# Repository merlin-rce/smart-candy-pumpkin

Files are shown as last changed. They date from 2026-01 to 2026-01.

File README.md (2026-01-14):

<div align="center">

# 🎃 The Smart Candy Pumpkin

**An ESP32-powered, motion-activated Halloween candy dispenser**






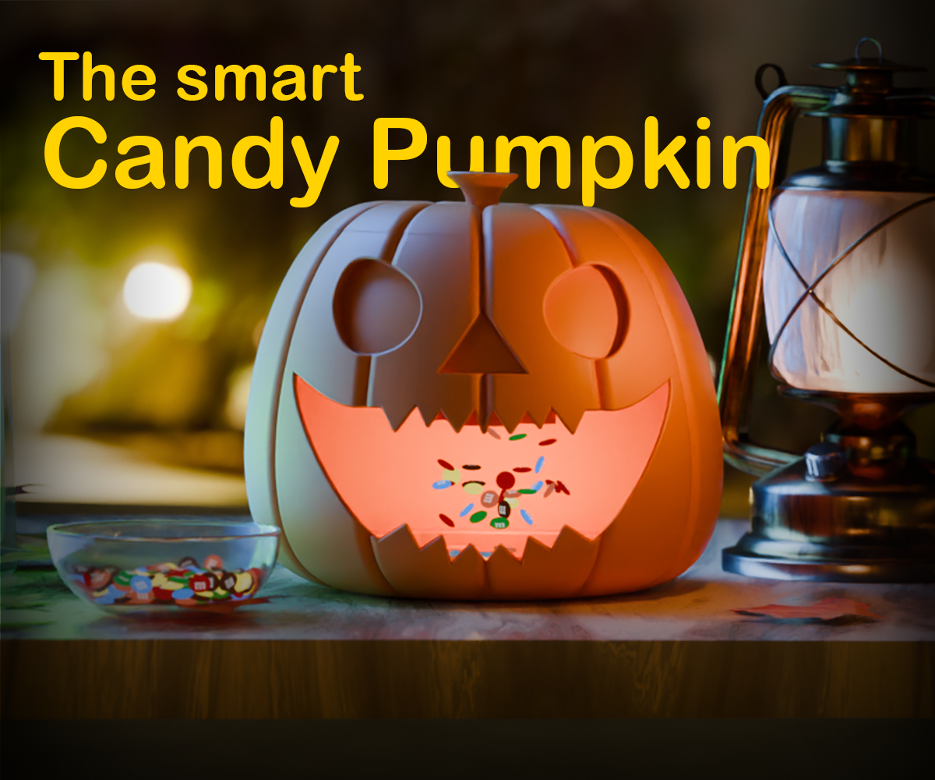
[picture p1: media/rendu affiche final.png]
Smart Candy Pumpkin


*A living, interactive pumpkin that surprises trick-or-treaters by automatically dispensing candy!*

[Features](#-features) • [Quick Start](#-quick-start) • [Build Guide](docs/BUILD_GUIDE.md) • [Parts List](#-bill-of-materials) • [3D Files](#-3d-printed-parts)

</div>

---

## 📖 About This Project

Halloween is that magical time of year when creativity meets fright — and candy flows like never before.

The **Smart Candy Pumpkin** is a motion-activated, ESP32-powered pumpkin that automatically dispenses candy when you place your hand inside its mouth. Inside, a hidden servo and ultrasonic sensor detect movement and trigger a rotating wheel that drops a handful of sweets.

> 🎓 **Made by students:** We're two 17-year-old students from Switzerland, passionate about electronics, 3D printing, and creative projects. This is our first full project!

| Difficulty | Build Time | Cost |
|:---:|:---:|:----:|
| ★★★☆☆ Intermediate | 4–6 hours | ~25–40 € |

---

## ✨ Features

- 🖐️ **Motion Detection** — Ultrasonic sensor triggers when a hand enters
- ⚙️ **Automatic Dispensing** — Servo-driven wheel releases candy portions
- 🔋 **Rechargeable** — USB-C charging with 10000mAh Li-Po battery
- 🎨 **Fully 3D Printed** — Complete enclosure with modular design
- 📱 **ESP32-S3 Powered** — Modern microcontroller with plenty of room for expansion
- 🔧 **Easy to Build** — Designed for makers of all levels

---

## 🔧 How It Works

```
┌─────────────────────────────────────────────────────────────┐
│                    SMART CANDY PUMPKIN                      │
├─────────────────────────────────────────────────────────────┤
│                                                             │
│   ┌───────────┐    ┌──────────┐    ┌──────────┐             │
│   │ Ultrasonic│──▶│   ESP32  │───▶│  Servo   │             │
│   │  Sensor   │    │   S3     │    │  Motor   │             │
│   └───────────┘    └──────────┘    └──────────┘             │
│        │                │              │                    │
│   Detects hand    Processes      Rotates candy              │
│   < threshold      signal          wheel                    │
│                                                             │
│   ┌────────────────────────────────────────────┐            │
│   │     Power System (3.7V → 5V)               │            │
│   │  Li-Po ──▶ TP4056 ──▶ DC Booster ──▶ 5V  │            │
│   └────────────────────────────────────────────┘            │
└─────────────────────────────────────────────────────────────┘
```

1. **Detection** — The HC-SR04 ultrasonic sensor continuously monitors the inside of the pumpkin
2. **Processing** — When distance drops below threshold, ESP32 triggers the dispensing sequence
3. **Dispensing** — The servo rotates the 3D-printed wheel, releasing candy through the mouth
4. **Reset** — System returns to monitoring mode, ready for the next trick-or-treater

---

## 🚀 Quick Start

### Prerequisites

- Arduino IDE or PlatformIO
- ESP32 board support installed
- Required libraries: `ESP32Servo`, `Ultrasonic`

### Installation

```bash
# Clone the repository
git clone https://github.com/yourusername/smart-candy-pumpkin.git
cd smart-candy-pumpkin

# Open in Arduino IDE or PlatformIO
# Select board: ESP32S3 Dev Module
# Upload the code
```

### Pin Configuration

| Component | Pin | Wire Color |
|---|-----|---|
| Servo Signal | GPIO 14 | White/Yellow |
| Ultrasonic TRIG | GPIO 16 | Blue |
| Ultrasonic ECHO | GPIO 15 | Yellow |
| Servo VCC | 5V (from booster) | Red |
| Servo GND | GND | Black |
| Sensor VCC | 5V (from booster) | Red |
| Sensor GND | GND | Black |

---

## 📦 Bill of Materials

### ⚡ Power & Charging

| Component | Qty | Link |
|---|:---:|---|
| Type-C Li-Po Charging Module (TP4056 HW-373) | 1 | [AliExpress](https://shorturl.at/nKeuP) |
| 3.7V Li-Po Battery (10000mAh) | 1 | [AliExpress](https://shorturl.at/S42xR) |
| DC-DC Step-Up Converter MT3608 (5V output) | 1 | [AliExpress](https://shorturl.at/hy9fU) |
| Mini Toggle Switch | 1 | — |
| USB Type-C Cable | 1 | — |

### 🧠 Control & Sensors

| Component | Qty | Link |
|---|:---:|---|
| ESP32-S3 Dev Board (N16R8 solderless) | 1 | [AliExpress](https://shorturl.at/64Qph) |
| HC-SR04 Ultrasonic Sensor | 1 | [AliExpress](https://shorturl.at/7jW49) |
| Servo Motor (SG90 or MG90S) | 1 | [AliExpress](https://shorturl.at/Mjuy7) |

### 🖨️ 3D Printing & Hardware

| Component | Qty | Link |
|---|:---:|---|
| PLA Filament Orange (~800g) | 1 | [BambuLab PLA Matte](https://shorturl.at/Oiv1V) |
| PLA Filament Green (small amount) | 1 | — |
| PLA Filament Black (small amount) | 1 | — |
| Round Magnets D6x2mm | 6-8 | [BambuLab Magnets](https://eu.store.bambulab.com/) |

### 🔧 Tools

- Soldering station + solder wire
- Wire cutter / stripper
- Heat-shrink tubing assortment
- Hot glue gun
- Multimeter (recommended)
- 3D Printer access

---

## 🖨️ 3D Printed Parts

All STL files are located in the [`3d-models/`](3d-models/) folder:

| Part | File | Quantity | Color |
|---|---|:---:|---|
| Bottom Base | [`Bottom Base.stl`](3d-models/Bottom%20Base.stl) | 1 | Orange |
| Inner Cover | [`Inner Cover.stl`](3d-models/Inner%20Cover.stl) | 1 | Orange |
| Mid-Mouth Section | [`Mid-Mouth Section.stl`](3d-models/Mid-Mouth%20Section.stl) | 1 | Orange |
| Upper Mouth Section | [`Upper Mouth Section.stl`](3d-models/Upper%20Mouth%20Section.stl) | 1 | Orange |
| Candy Funnel Top | [`Candy Funnel Top.stl`](3d-models/Candy%20Funnel%20Top.stl) | 1 | Orange |
| Stem Cap | [`Stem Cap.stl`](3d-models/Stem%20Cap.stl) | 1 | Green |
| Servo Wheel | [`Servo Wheel.stl`](3d-models/Servo%20Wheel.stl) | 1 | Black |
| Alignment Connector | [`Alignement Connector.stl`](3d-models/Alignement%20Connector.stl) | 6 | Orange |

### Print Settings

| Setting | Value |
|---|---|
| Layer Height | 0.16 mm |
| Infill | 15–20% |
| Supports | Yes (except cable channels) |
| Total Time | ~22 hours |
| Total Filament | ~800g |

> 📥 **Ready-to-print profiles available on [MakerWorld](https://makerworld.com/fr/models/1973808-the-smart-candy-pumpkin)**

---

## 💻 Code

The Arduino sketch is located in the `code/` folder. See the full code in [`code/Smart_Candy_Pumpkin.ino`](code/Smart_Candy_Pumpkin.ino).

### Key Configuration

```cpp
#define SERVO_PIN       14    // Servo signal pin
#define TRIG_PIN        16    // Ultrasonic trigger
#define ECHO_PIN        15    // Ultrasonic echo
#define DIST_THRESHOLD  15    // Detection distance (cm)
```

### Required Libraries

Install via Arduino Library Manager:
- **ESP32Servo** by Kevin Harrington & John K. Bennett
- **Ultrasonic** by Erick Simões

### Upload Instructions

1. Open Arduino IDE
2. Go to **File → Preferences** and add ESP32 board URL:
   ```
   https://raw.githubusercontent.com/espressif/arduino-esp32/gh-pages/package_esp32_index.json
   ```
3. Install ESP32 board package via **Tools → Board → Boards Manager**
4. Select **ESP32S3 Dev Module**
5. Connect via USB and select the correct port
6. Click **Upload** (hold BOOT button if needed)

---

## ⚠️ Safety Notes

> **This project involves electronics, soldering, and Li-Po batteries. Please read carefully.**

| ⚡ Electrical | 🔋 Battery | 🔥 Soldering |
|---|---|---|
| Always unplug before wiring | Never puncture or bend | Wear safety glasses |
| Double-check polarity (+/–) | Don't charge unattended | Work in ventilated area |
| Use multimeter to verify | Keep away from heat | Use proper iron stand |

---

## 🗂️ Repository Structure

```
smart-candy-pumpkin/
├── 📄 README.md                    # This file
├── 📄 LICENSE                      # CC BY-NC-SA 4.0
├── 📁 code/                        # Arduino source code
│   └── Smart_Candy_Pumpkin.ino
├── 📁 docs/                        # Documentation
│   └── BUILD_GUIDE.md              # Step-by-step build guide
├── 📁 3d-models/                   # All 3D printable STL files
│   ├── Bottom Base.stl
│   ├── Inner Cover.stl
│   ├── Mid-Mouth Section.stl
│   ├── Upper Mouth Section.stl
│   ├── Candy Funnel Top.stl
│   ├── Stem Cap.stl
│   ├── Servo Wheel.stl
│   └── Alignement Connector.stl
├── 📁 media/                       # Renders & videos
│   ├── rendu *.png                 # 3D renders
│   └── animation *.mp4             # Demo video
└── 📁 .github/
    └── FUNDING.yml                 # Sponsorship info
```

---

## 🔮 Future Improvements

- [ ] Adjustable candy portion size
- [ ] LED eyes with spooky effects
- [ ] Sound effects (screams, laughs)
- [ ] Power-saving deep sleep mode
- [ ] Wi-Fi configuration portal
- [ ] Candy count tracker

---

## 🙏 Acknowledgments

- **3D Renders:** Kwama Muhoto Tevin — for the amazing visuals
- **Workshop Support:** CPNE – ELN Department — for tools and materials
- **Build Assistance:** Alessio Castorina — for the help and fast deliveries

---

## 📚 Resources

| Resource | Description |
|---|---|
| 📖 [Build Guide](docs/BUILD_GUIDE.md) | Detailed step-by-step instructions |
| 🌐 [Instructables](https://www.instructables.com/The-Smart-Candy-Pumpkin/) | Original tutorial with time-lapse videos |
| 🔌 [Circuit Diagram](https://app.cirkitdesigner.com/project/bdcf653b-0cb5-4596-8416-652c75baebec) | Interactive wiring schematic |
| 🖨️ [MakerWorld](https://makerworld.com/fr/models/1973808-the-smart-candy-pumpkin) | Ready-to-print slicer profiles |

---

## 📜 License

This project is licensed under **[CC BY-NC-SA 4.0](https://creativecommons.org/licenses/by-nc-sa/4.0/)** — see the [LICENSE](LICENSE) file for details.

You are free to share and adapt this project for **non-commercial purposes**, as long as you give appropriate credit and share your modifications under the same license.

---

<div align="center">

**Made with ❤️ in Switzerland**

If you enjoyed this project, consider supporting us!



⭐ **Star this repo** if you found it helpful!

</div>

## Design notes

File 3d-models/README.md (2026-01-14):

# 🖨️ 3D Models

This folder contains all the STL files needed to print the Smart Candy Pumpkin.

## Parts List

| File | Quantity | Color | Description |
|---|:---:|---|---|
| `Bottom Base.stl` | 1 | 🟠 Orange | Holds battery, ESP32, and electronics |
| `Inner Cover.stl` | 1 | 🟠 Orange | Hides electronics (removable) |
| `Mid-Mouth Section.stl` | 1 | 🟠 Orange | Contains servo, sensor, and candy chute |
| `Upper Mouth Section.stl` | 1 | 🟠 Orange | Top of mouth with eyes |
| `Candy Funnel Top.stl` | 1 | 🟠 Orange | Where you pour candies in |
| `Stem Cap.stl` | 1 | 🟢 Green | The pumpkin stem |
| `Servo Wheel.stl` | 1 | ⚫ Black | Rotating disk that releases candy |
| `Alignement Connector.stl` | 6 | 🟠 Orange | Connects sections together |

## Print Settings

| Setting | Recommended Value |
|---|---|
| Material | PLA |
| Layer Height | 0.16 mm |
| Infill | 15–20% |
| Supports | Yes (see note below) |
| Build Plate | Textured preferred |

> ⚠️ **Important:** Disable supports inside the cable management channel of the Bottom Base, otherwise wires won't fit through!

## Print Stats

- ⏱️ **Total time:** ~22 hours
- 🧵 **Filament used:** ~800g

## Ready-to-Print Profiles

Pre-configured slicer profiles for Bambu Lab printers are available on MakerWorld:

👉 [Download from MakerWorld](https://makerworld.com/fr/models/1973808-the-smart-candy-pumpkin)

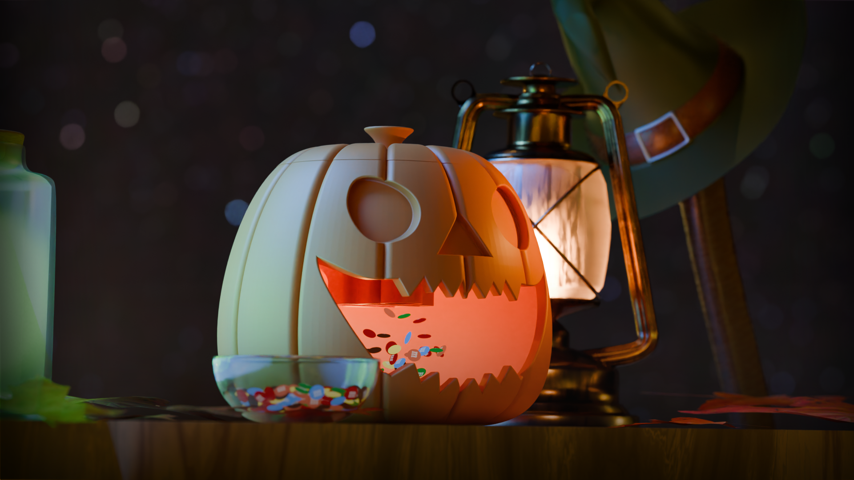
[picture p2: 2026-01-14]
media/rendu 8 effet.png

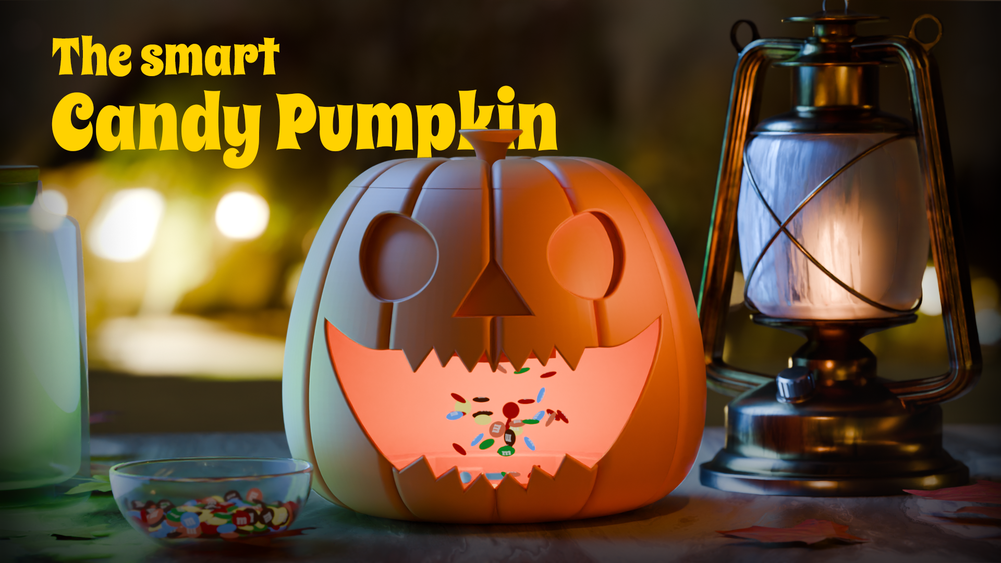
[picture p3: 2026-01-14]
media/affiche variante (1920 x 1080).png

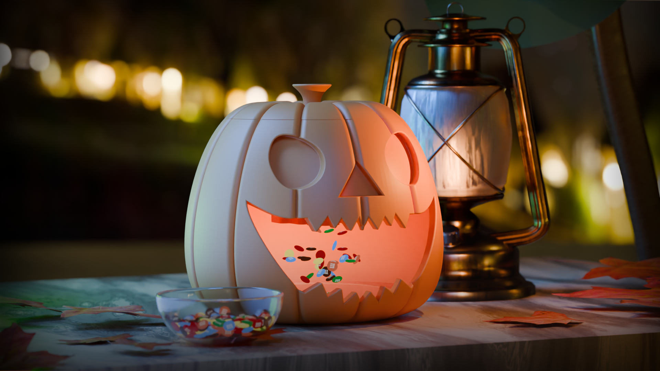
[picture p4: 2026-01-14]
media/rendu 1 effet.png

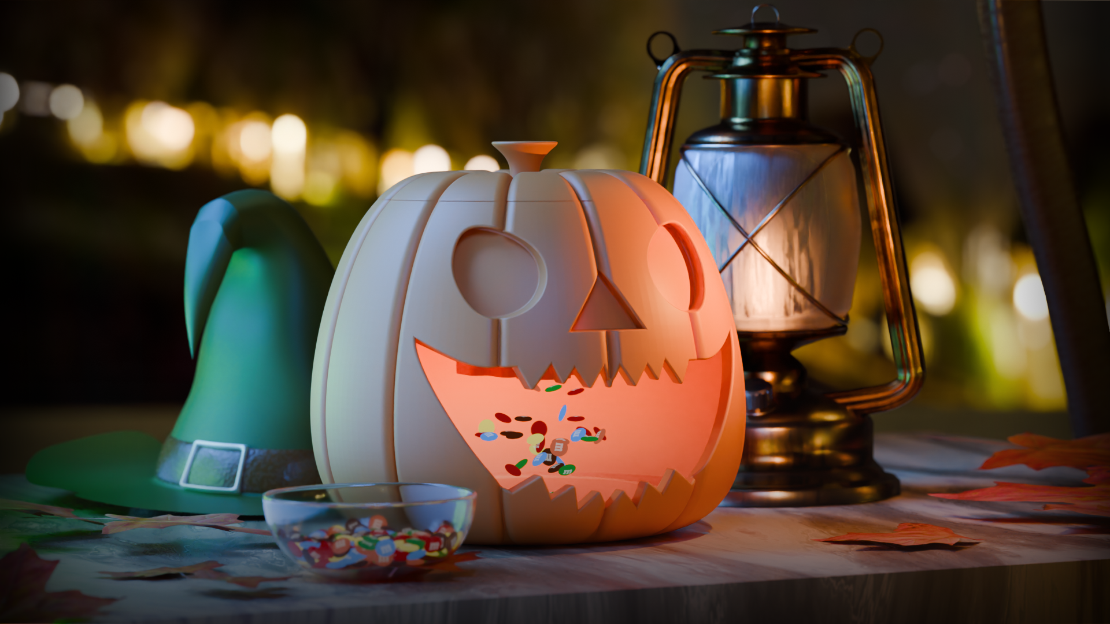
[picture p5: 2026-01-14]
media/rendu 2 effet.png

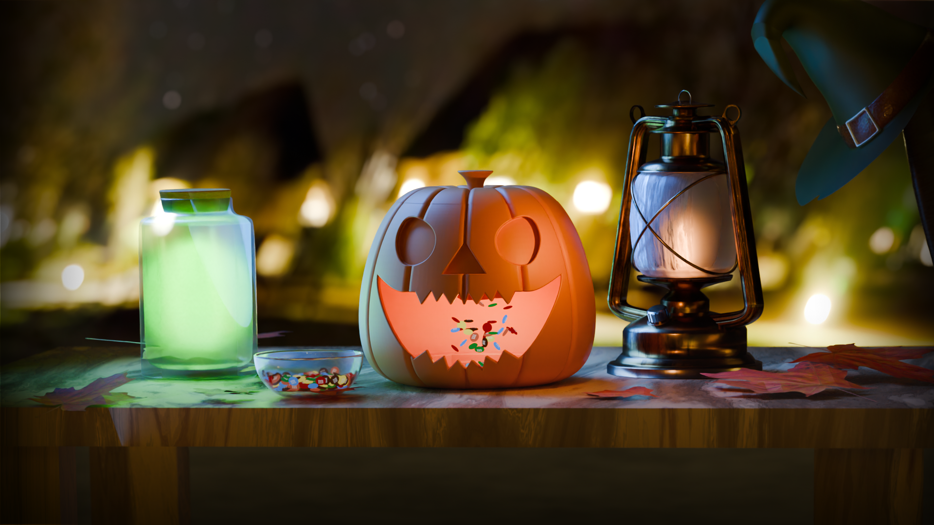
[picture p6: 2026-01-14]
media/rendu 5 effet.png

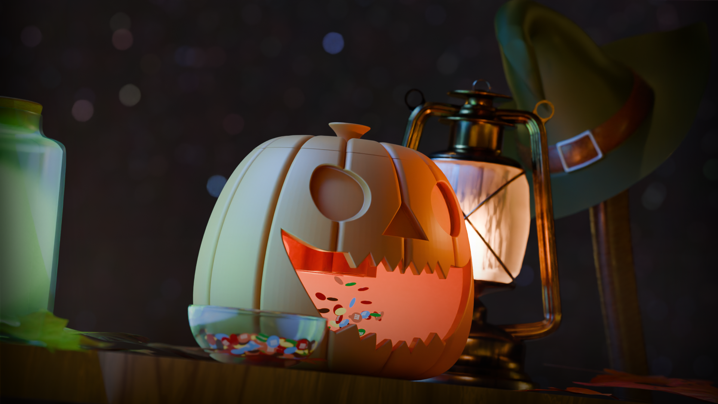
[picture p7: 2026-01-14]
media/rendu 7 effet.png

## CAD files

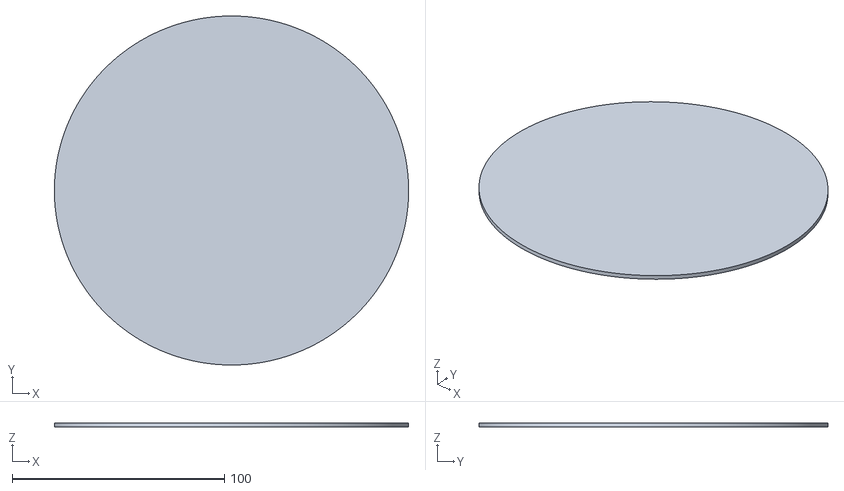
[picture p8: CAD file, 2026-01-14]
3d-models/Inner Cover.stl
167.0 x 164.6 x 2.00

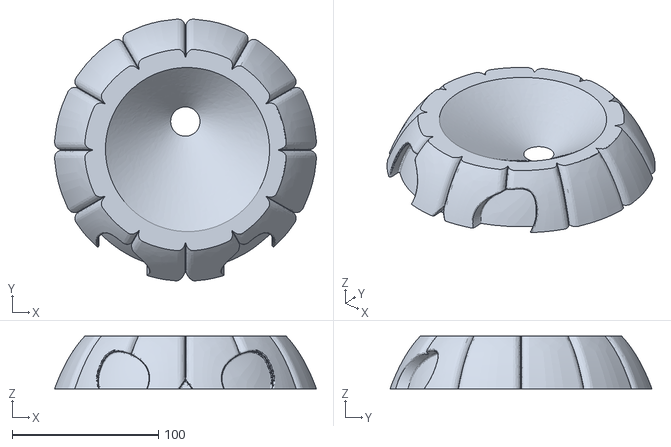
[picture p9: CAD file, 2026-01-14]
3d-models/Upper Mouth Section.stl
179.0 x 179.0 x 36.1

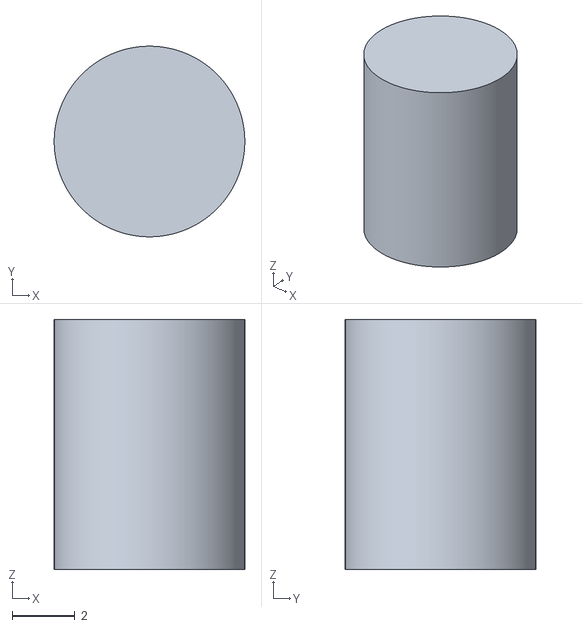
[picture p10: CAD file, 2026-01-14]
3d-models/Alignement Connector.stl
6.10 x 6.10 x 8.00

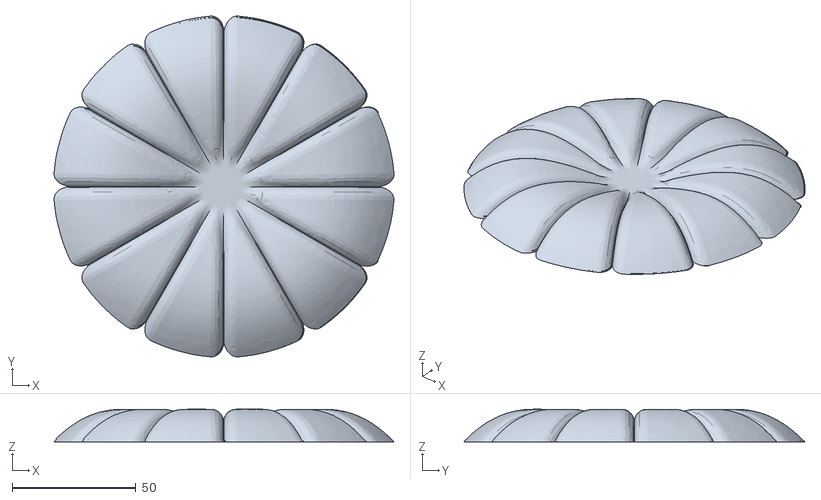
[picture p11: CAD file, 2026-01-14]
3d-models/Candy Funnel Top.stl
137.2 x 137.5 x 13.1

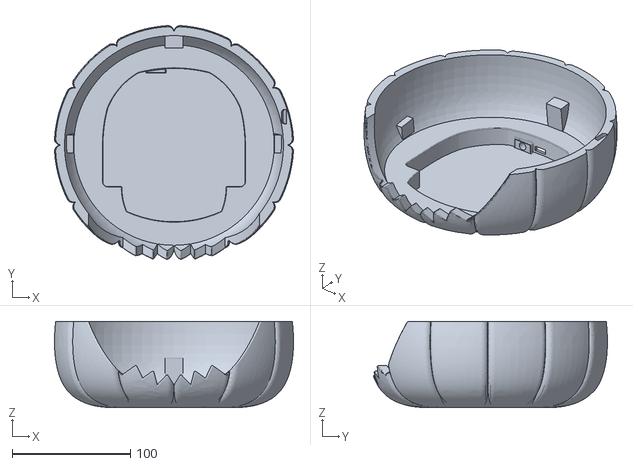
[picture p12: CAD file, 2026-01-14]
3d-models/Bottom Base.stl
202.0 x 197.6 x 72.7

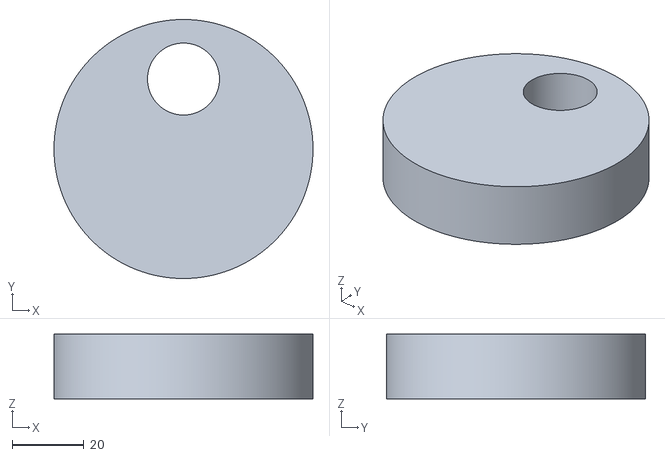
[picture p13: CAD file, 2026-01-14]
3d-models/Servo Wheel.stl
72.0 x 72.0 x 18.0

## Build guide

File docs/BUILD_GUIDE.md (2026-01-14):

# 📖 Smart Candy Pumpkin — Complete Build Guide

This guide contains detailed step-by-step instructions for building the Smart Candy Pumpkin from start to finish.

> 🎥 **Video tutorials available:** Check out our [Instructables page](https://www.instructables.com/The-Smart-Candy-Pumpkin-/) for time-lapse videos of each step.

---

## Table of Contents

1. [Safety & Preparation](#1-safety--preparation)
2. [Wiring Overview](#2-wiring-overview)
3. [Adding the Power Switch](#3-adding-the-power-switch)
4. [Connecting Charger to DC Booster](#4-connecting-the-charger-to-the-dc-booster)
5. [Connecting Battery to Charger](#5-connecting-the-battery-to-the-charging-module)
6. [Wiring the Ultrasonic Sensor](#6-wiring-the-ultrasonic-sensor)
7. [Preparing the Servo Connection](#7-preparing-the-servo-connection)
8. [Power Wiring to Booster](#8-power-wiring-servo--sensor-to-the-booster)
9. [Wiring to ESP32](#9-wiring-everything-to-the-esp32)
10. [Uploading the Code](#10-uploading-the-code-to-the-esp32)
11. [3D Printing](#11-3d-printing-the-pumpkin)
12. [Gluing Stem & Placing Magnets](#12-gluing-the-pumpkin-stem-and-placing-magnets)
13. [Assembling Candy Funnel](#13-assembling-the-candy-funnel-with-upper-mouth-section)
14. [Routing Wires](#14-routing-the-wires-to-the-bottom-base)
15. [Mounting Electronics](#15-mounting-the-electronics-in-the-bottom-base)
16. [Final Assembly](#16-final-pumpkin-assembly)
17. [Testing & Completion](#17-the-pumpkin-comes-to-life)

---

## 1. Safety & Preparation

Before bringing your pumpkin to life, let's make sure everything stays safe — both for you and your workspace.

### ⚠️ Safety Guidelines

| Category | Precautions |
|---|---|
| **Electrical** | Always unplug power before wiring or soldering. Double-check all battery polarities (+/–). |
| **Li-Po Battery** | Handle with care — never bend, puncture, or charge unattended. Place on non-flammable surface while charging. |
| **Soldering** | Wear protective glasses, work in ventilated area, use proper stand for your iron. |
| **3D Printing** | Let parts cool completely before assembly. Trim off sharp edges or support marks. |

### 💡 Pro Tips

- A multimeter is your best friend — always check voltage before powering your ESP32
- Hot glue and Li-Po cells don't mix! Keep glue away from batteries and wires

---

## 2. Wiring Overview

Before starting the build, here's how every component connects together.

### 📐 Full Circuit Diagram

👉 **Interactive circuit:** [View on Cirkit Designer](https://app.cirkitdesigner.com/project/bdcf653b-0cb5-4596-8416-652c75baebec)

### Pin Connections

#### Servo Motor
| Wire | Connection |
|---|---|
| White (Signal) | GPIO 14 on ESP32 |
| Red (VCC) | 5V output from booster |
| Black (GND) | GND output from booster |

#### Ultrasonic Sensor (HC-SR04)
| Pin | Connection |
|-----|---|
| VCC | 5V output from booster |
| GND | GND output from booster |
| TRIG | GPIO 16 (blue wire) |
| ECHO | GPIO 15 (yellow wire) |

#### Power System
```
Battery (3.7V) → HW-373 Type-C Charger
├── Red (+) → B+
└── Black (–) → B-

HW-373 Output → MT3608 Booster Input
├── OUT+ → VIN+ (red)
└── OUT– → VIN– (black)
```

> 🧠 **Tip:** Always double-check the polarity (+/–) before powering on. A wrong connection can damage the ESP32 or booster.

---

## 3. Adding the Power Switch

We're adding a small toggle switch to control power between the battery and the circuit.

### Steps

1. **Trim the switch** — It's a 3-pin toggle. Cut off the third pin (unused)
2. **Cut the battery's red wire** in half. You now have two ends: one from the battery, one going to the circuit
3. **Strip & tin** both ends with a bit of solder
4. **Slide heat-shrink tube** on the battery side before soldering
5. **Solder connections:**
   - Battery wire → left lug
   - Circuit wire → right lug
6. **Shrink the tubing** with a lighter — quick passes, no flames near the Li-Po!

✅ You now have a clean power switch inline with the battery.

---

## 4. Connecting the Charger to the DC Booster

Linking the Type-C charging module to the DC-DC booster for 5V output.

### Steps

1. **Prepare two short wires** — just long enough from charger to booster
2. **Strip and tin** both ends of each wire
3. **Solder to charging module** — use the output pads (NOT BAT+/BAT–)
4. **Solder to DC booster** — VIN+ and VIN– pads
5. **Verify polarity:** + → +, – → –
6. **Adjust output voltage:**
   - Plug USB-C cable into charger
   - Use small screwdriver to turn the adjustment screw
   - Adjust until output reads **5.0V** (check with multimeter)
7. **Add heat-shrink tubing** for insulation

✅ Charger and booster now deliver clean 5V output!

---

## 5. Connecting the Battery to the Charging Module

Soldering the Li-Po battery directly to the Type-C charging board.

### Steps

1. Take the battery leads:
   - **Red = +**
   - **Black = –**
2. **Tin both ends**
3. **Solder:**
   - Red → B+
   - Black → B–
4. **Add heat-shrink** before soldering, then slide over joints
5. **Shrink carefully** with lighter — short passes, keep flame away from Li-Po!

✅ Battery is now safely connected to the charger.

---

## 6. Wiring the Ultrasonic Sensor

Preparing clean, removable connections for the HC-SR04 sensor.

### Steps

1. **Prepare 4-wire ribbon cable** (red, black, yellow, blue) with female connector end
2. **Tin all four wires** on the open side
3. **Remove default header** from sensor by adding solder to pins
4. **Solder wires directly to sensor:**
   | Pin | Wire Color |
   |-----|------------|
   | VCC | Red 🔴 |
   | GND | Black ⚫ |
   | Echo | Yellow 🟡 |
   | Trig | Blue 🔵 |
5. **Prepare male pins:** Take 4 male-to-male pins, tin shorter side
6. **Solder each color wire** to matching pin
7. **Add heat-shrink** over every joint

✅ You now have a plug-and-play ultrasonic sensor cable!

---

## 7. Preparing the Servo Connection

Creating a detachable connector for the servo motor.

### Steps

1. **Cut three short wires:** black, red, yellow
2. **Strip and tin** both ends of each wire
3. **Take three male-to-male pins** and solder wires to short side
4. **Add heat-shrink tubing** and shrink with lighter
5. **Match colors on servo side:**
   | Servo Wire | Your Wire |
   |------------|-----------|
   | Black | Black ⚫ |
   | Red | Red 🔴 |
   | White | Yellow 🟡 |

✅ You have a detachable 3-pin servo connector!

---

## 8. Power Wiring: Servo + Sensor to the Booster

Connecting 5V and GND for servo and sensor to the DC booster output.

### Steps

**For 5V (Red wires):**
1. Take red wire from servo + red wire from sensor + extra red wire (for ESP32)
2. Strip and tin loose ends
3. Twist all three red wires together
4. Slide small heat-shrink behind them
5. Solder bundle to **V-OUT+** pad on DC booster
6. Add larger heat-shrink over the group

**For GND (Black wires):**
1. Repeat same process with black wires
2. Twist together, tin, solder to **V-OUT–**
3. Finish with heat-shrink tubing

✅ Servo, sensor, and ESP32 now share 5V and ground from booster!

---

## 9. Wiring Everything to the ESP32

Final soldering connections to the ESP32 board.

### Signal Connections

| Wire | ESP32 Pin |
|---|---|
| Trigger (blue) | GPIO 16 |
| Echo (yellow) | GPIO 15 |
| Servo signal (yellow) | GPIO 14 |

### Power Connections

| Wire | ESP32 Pin |
|---|---|
| Red (from booster V-OUT+) | 5V |
| Black (from booster V-OUT–) | GND |

### Steps

1. **Tin each wire**
2. **Insert through corresponding hole** on ESP32
3. **Solder from back side**
4. **Trim wire ends** so they don't stick out

> ⚠️ **Tip:** Keep all connections on the same side of the board for clean, flat assembly.

✅ ESP32 is fully wired and ready!

---

## 10. Uploading the Code to the ESP32

Time to give your pumpkin a brain! 🧠🎃

### Step 1: Install Arduino IDE

Download from [arduino.cc](https://www.arduino.cc/en/software)

### Step 2: Add ESP32 Board Support

1. Open Arduino IDE → **File → Preferences**
2. In "Additional Boards Manager URLs", paste:
   ```
   https://raw.githubusercontent.com/espressif/arduino-esp32/gh-pages/package_esp32_index.json
   ```
3. Click OK

### Step 3: Install ESP32 Package

1. Go to **Tools → Board → Boards Manager**
2. Search for "esp32"
3. Install package by **Espressif Systems**
4. Select **Tools → Board → ESP32 Arduino → ESP32S3 Dev Module**

### Step 4: Install Required Libraries

Go to **Sketch → Include Library → Manage Libraries** and install:
- **ESP32Servo** by Kevin Harrington & John K. Bennett
- **Ultrasonic** by Erick Simões

### Step 5: Configure the Code

Open `code/Smart_Candy_Pumpkin.ino` and verify pins match your build:
```cpp
#define SERVO_PIN       14
#define TRIG_PIN        16
#define ECHO_PIN        15
#define DIST_THRESHOLD  15  // cm
```

### Step 6: Upload

1. Connect ESP32 via USB (use the USB port, not UART)
2. Select correct port under **Tools → Port**
3. Click **Upload (▶)**
4. If upload doesn't start, hold **BOOT** button until flashing begins

### Testing

1. Open **Serial Monitor** (115200 baud)
2. Move hand inside pumpkin area
3. Servo should spin and "drop candy"

✅ ESP32 is programmed!

---

## 11. 3D Printing the Pumpkin

The model is split into 8 printable parts for easy assembly.

### Parts List

| Part | Color | Qty |
|---|---|:---:|
| Bottom Base | Orange 🟠 | 1 |
| Inner Cover | Orange 🟠 | 1 |
| Mid-Mouth Section | Orange 🟠 | 1 |
| Upper Mouth Section | Orange 🟠 | 1 |
| Candy Funnel Top | Orange 🟠 | 1 |
| Stem Cap | Green 🟢 | 1 |
| Servo Wheel | Black ⚫ | 1 |
| Alignment Connector | Orange 🟠 | 6 |

### Print Settings

| Setting | Value |
|---|---|
| Layer Height | 0.16 mm |
| Infill | 15–20% |
| Plate | Textured build plate |
| Supports | Normal (see note below) |

> ⚠️ **Important:** Disable supports inside the cable management area of the Bottom Base — otherwise wires won't fit through!

### Stats

- ⏱️ Total print time: ~22 hours (Bambu Lab P1S)
- 🧵 Filament used: ~800g PLA

### Download Files

- STL files included in repository root
- Ready-to-print profiles: [MakerWorld](https://makerworld.com/fr/models/1973808-the-smart-candy-pumpkin)

✅ Print all parts before continuing!

---

## 12. Gluing the Pumpkin Stem and Placing Magnets

### Attaching the Stem

1. Take the small **green stem**
2. Apply small drop of **super glue** to center of top cap
3. Press firmly for a few seconds
4. Let dry

### Placing the Magnets

The underside of the top cap has small round holes for magnets.

> ⚠️ **Critical:** Check magnet polarity before inserting!

1. Take two magnets and stick them together (shows attracting faces)
2. Slide one magnet into hole (should fit snugly)
3. For matching part, use second magnet (still attached) to find correct orientation
4. Separate gently and insert second magnet

> ✨ No glue needed — friction fit holds them in place!

---

## 13. Assembling the Candy Funnel with Upper Mouth Section

### Steps

1. **Place servo motor** into dedicated slot in Mid-Mouth Section
2. **Insert black Servo Wheel** from other side
3. **Secure with screw** from servo kit
   - ⚠️ Don't overtighten — servo needs to rotate freely!
4. **Insert ultrasonic sensor** into its opening
5. **Pass wires** through cable hole behind it
6. **Add double-sided tape** under sensor to secure (no tape under servo!)
7. **Align Candy Funnel Top** with Upper Mouth Section
8. **Insert plastic connection cylinders** into large holes
9. **Apply glue** on cylinders
10. **Press parts together** firmly until glue sets

> ⚠️ Don't attach this assembly to rest of pumpkin yet!

✅ Servo and sensor installed, funnel attached!

---

## 14. Routing the Wires to the Bottom Base

Passing all wires through the built-in cable tunnel.

### Steps

1. Take a piece of **fishing line** (or thin strong wire)
2. **Tie servo and sensor wires** together at one end of fishing line
3. From Bottom Base, **feed fishing line up** through cable passage
4. **Pull fishing line back down**, bringing wires with it
   - Go slowly — passage is tight!
5. **Tape or glue wires** along top edge inside pumpkin

✅ Wires routed cleanly from top to bottom!

---

## 15. Mounting the Electronics in the Bottom Base

### Placement

1. **Battery** — Stick in center with double-sided tape. Route cables behind it.
2. **ESP32** — Place at bottom, secure with tape
3. **Power switch** — Insert into side hole
4. **Charging module** — Mount in slot, align USB-C port with external hole
5. **DC booster** — Stick next to charger with tape
6. **Flatten wires** along walls for clean finish

✅ All electronics securely placed!

---

## 16. Final Pumpkin Assembly

### Steps

1. Place **Inner Cover** — rests on inner ledge in Bottom Base
   - ⚠️ Don't glue! Keeps it removable for maintenance
2. Take **Bottom Base** and **Mid-Mouth Section**
3. Insert **plastic connection cylinders** into large holes
4. Apply **small drop of glue** on each cylinder
5. **Press parts together** carefully until aligned
6. Hold a few seconds for glue to set

✅ Pumpkin body fully assembled!

---

## 17. The Pumpkin Comes to Life!

🎉 **Congratulations!** Your Smart Candy Pumpkin is complete!

### Final Steps

1. Fill the funnel with M&M's or your favorite candies 🍬
2. Flip the power switch
3. Watch the magic happen!

### Troubleshooting

| Issue | Solution |
|---|---|
| Servo doesn't move | Check wiring, verify 5V from booster |
| No detection | Adjust `DIST_THRESHOLD` in code |
| Servo moves wrong direction | Swap open/close angles in code |
| ESP32 won't upload | Hold BOOT button during upload |

---

## 🎃 Enjoy Your Creation!

You've built a full Halloween robot — great job! 👏

### Share Your Build

- 💬 Leave a comment on our [Instructables page](https://www.instructables.com/The-Smart-Candy-Pumpkin/)
- ☕ [Support us on Buy Me a Coffee](https://buymeacoffee.com/uztiota)
- ⭐ Star this repository!

---

*Made with 🎃 in Switzerland*
